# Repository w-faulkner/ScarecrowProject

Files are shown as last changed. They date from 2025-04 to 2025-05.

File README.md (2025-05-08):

# Automated Scarecrow
***
### By: Jacob Crabtree, Will Faulkner, Lauren Lanham, and Rianna Mueller
### BAE 305
### Spring 2025
***
## Summary
&nbsp;&nbsp;&nbsp;&nbsp; The objective of this project was to design and implement an automated scarecrow system intended to assist farmers in deterring birds and minimizing crop yield losses. The system integrates a passive infrared (PIR) motion sensor, mounted on the head of the scarecrow. The PIR sensor can detect thermal movement from birds or other heat-emitting objects within its field of view. Upon motion detection, the system initiates a sequence that activates the DC motors that drive the movement of the scarecrow’s arms and legs, while a set of LEDs embedded in the head light up to enhance the scare effect. To provide mobility and remote operation, the entire scarecrow assembly is mounted on a motorized, remote-controlled (RC) platform. This platform is driven by two DC hobby gear motors, which are connected to a wireless control interface. The RC car is capable of multidirectional movement (forward, backward, left, and right) controlled by a handheld transmitter. This mobility allows the operator to reposition the scarecrow across a field or garden, which increases its effective coverage area and adaptability to different farming environments. The video that includes all the features of our automated scarecrow can be found [here](https://vimeo.com/1079489157/0302ad2d24?ts=0&share=copy).

<figure>  
<p align="left">  
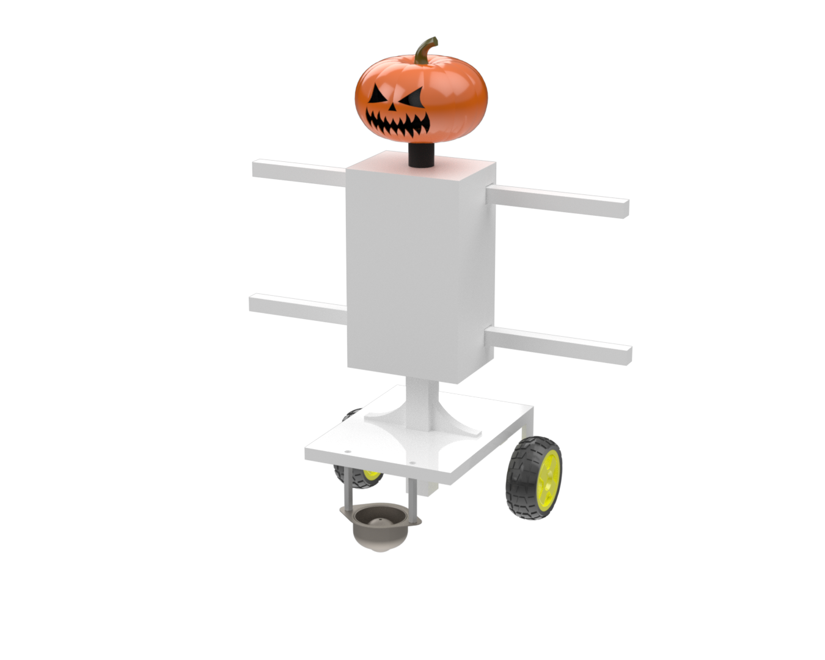
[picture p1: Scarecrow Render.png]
Scarecrow
  
<figcaption> <h6> Figure 1. The final model rendering of our scarecrow build. </figcaption>  
</figure>  
</p>  

## Design 
&nbsp;&nbsp;&nbsp;&nbsp; The automated scarecrow can be broken down into three parts: scarecrow design, the remote-controlled (RC) car, and wiring. All 3D-printable files and code are linked and can also be found in the files of this repository.
### Scarecrow

#### Materials 

* [3D printed block](https://github.com/w-faulkner/ScarecrowProject/blob/main/Modeling%20Files/block.stl)
* [3D printed bottom plate](https://github.com/w-faulkner/ScarecrowProject/blob/main/Modeling%20Files/bottomplate.stl)
* [3D printed cover](https://github.com/w-faulkner/ScarecrowProject/blob/main/Modeling%20Files/cover.stl)
* [3D printed head](https://github.com/w-faulkner/ScarecrowProject/blob/main/Modeling%20Files/head.stl)
* [3D printed main body](https://github.com/w-faulkner/ScarecrowProject/blob/main/Modeling%20Files/mainboyd.stl)
* [3D printed neck](https://github.com/w-faulkner/ScarecrowProject/blob/main/Modeling%20Files/neck.stl)
* [3D printed pin](https://github.com/w-faulkner/ScarecrowProject/blob/main/Modeling%20Files/pin.stl)
* [3D printed pin cap](https://github.com/w-faulkner/ScarecrowProject/blob/main/Modeling%20Files/pincap.stl)
* [3D printed post](https://github.com/w-faulkner/ScarecrowProject/blob/main/Modeling%20Files/post.stl)
* [3D printed scotch](https://github.com/w-faulkner/ScarecrowProject/blob/main/Modeling%20Files/scotch.stl)
* [3D printed top plate](https://github.com/w-faulkner/ScarecrowProject/blob/main/Modeling%20Files/topplate.stl)
* [3D printed yoke](https://github.com/w-faulkner/ScarecrowProject/blob/main/Modeling%20Files/yoke.stl)
* 2 –  [1 ft bamboo square dowels](https://www.amazon.com/Lugailly-Square-Wood-Dowels-Woodworking/dp/B0CZJGM1Y3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)
* 4 - [Eye hooks](https://www.amazon.com/FramePac-Small-Screw-Short-Screweyes/dp/B07R837Y69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)
* 2 - [J-style hooks](https://www.amazon.com/IDEALSV-Antique-Ceiling-Vintage-Jewelry/dp/B089N325DP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)
* [Velcro](https://www.amazon.com/Adhesive-Interlocking-Fastener-Adhesion-reclosable/dp/B09HTT768S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)
* 2 – [RGB LED](https://www.sparkfun.com/led-assorted-20-pack.html)
* [AMS312 Mini Pyroelectric PIR Human Sensor Module](https://www.amazon.com/dp/B07RT7MK7C?ref=ppx_yo2ov_dt_b_fed_asin_title)
* 2 – [N20 D.C. gear motor](https://www.amazon.com/HiLetgo-GA12-N20-Reduction-Deceleration-Multiple/dp/B0CHRWJFMD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)
* [Super Glue](https://www.amazon.com/Gorilla-Super-Glue-gram-Clear/dp/B082XGL21J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) 

#### Build Procedure

&nbsp;&nbsp;&nbsp;&nbsp; The initial phase of the project focused on constructing the physical structure of the scarecrow. This began with CAD modeling and 3D printing all necessary components. To ensure structural integrity, the top and bottom plates were adhesively bonded to the central chassis of the scarecrow using super glue, allowing adequate curing time for secure attachment. For the articulation mechanism, pilot holes were drilled into each of the yoke spacers using a precision drill bit. These holes allowed for the insertion of small eye hooks, which serve as mechanical linkage points for the scarecrow’s limbs. The component initially labeled “block” in the CAD files was later renamed “yoke spacer” for clarity. The yoke assembly was then inserted and fixed into place with adhesive. A 3D-printed pin was inserted through the rear opening of the body, and the assembly components (yoke spacer, yoke, and pin cap) were sequentially mounted onto the pin. This procedure was repeated for both N20 gear motor assemblies, ensuring symmetric actuation of the limbs. Following the installation of the yoke mechanisms, the N20 gear motors were positioned into their respective motor housings and secured. Scotch yokes were then mounted onto the motor output shafts and mechanically linked to the yoke assemblies. Additional eye bolts were threaded into the pre-drilled holes on the yoke spacers to establish the attachment points for the limbs. A close-up image of the scotch yoke mechanism used can be seen in Figure 2. The limb assembly utilized 12-inch bamboo dowels, which were cut in half to form both the arms and legs. Each dowel segment had a pilot hole drilled at one end to allow for the installation of J-hooks. The dowels were inserted through designated openings on the main body, and the J-hooks were connected to the eye bolts on the yoke spacers, completing the limb articulation system. For the head unit, two LEDs were embedded into a pumpkin-shaped enclosure to simulate eyes, and a passive infrared (PIR) motion sensor was installed to detect thermal activity on top. The neck component was affixed to the bottom of the head and then bonded to the top of the main body using adhesive. A post was subsequently glued to the bottom of the body to provide additional structural support and integration with the mobile platform. To complete the assembly, Velcro strips were attached to both the main body and its removable cover. This allows the internal wiring and electronic components to be concealed while still enabling easy access for maintenance or adjustments.
<figure>  
<p align="left">  
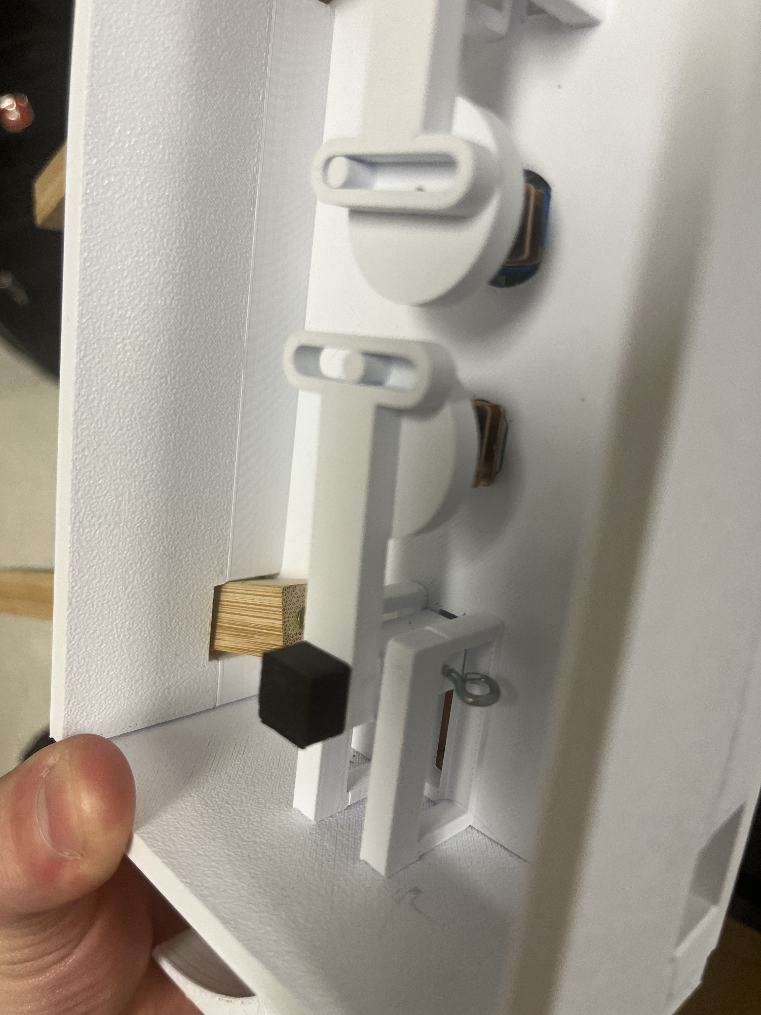
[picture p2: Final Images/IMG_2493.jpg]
  
<figcaption> <h6> Figure 2. An image of the scotch yoke mechanism used to move to arms and legs of the scarecrow. </figcaption>  
</figure>  
</p>  

### RC Car

#### Materials 

* [3D printed car base](https://github.com/w-faulkner/ScarecrowProject/blob/main/Modeling%20Files/car_base.stl)
* 2 – [140 RPM D.C. Hobby Gearmotors](https://www.sparkfun.com/hobby-gearmotor-140-rpm-pair.html)
* [Flange Mount Ball Transfer](https://www.mcmaster.com/5674K1/)
* [Female Threaded Hex Standoffs 1.5](https://www.mcmaster.com/91115A146/)
* [Velcro](https://www.amazon.com/Adhesive-Interlocking-Fastener-Adhesion-reclosable/dp/B09HTT768S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)
* 2 - [65 mm wheels](https://www.sparkfun.com/wheel-65mm-rubber-tire-pair.html)
* 4 – [10-32 Machine Screws](https://www.mcmaster.com/90272A829/)

#### Build Procedure 

&nbsp;&nbsp;&nbsp;&nbsp; The construction of the RC car base for the scarecrow platform involved a straightforward mechanical integration of components. A flange-mounted ball transfer unit was affixed to a pair of hex standoffs using two 10-32 machine screws. The opposing ends of the hex standoffs were then secured to the baseplate of the RC platform using an additional pair of 10-32 machine screws, forming a stable tricycle-style support configuration. To mount the DC hobby gear motors, Velcro strips were applied to both the flat surface of each motor casing and the inner surfaces of their respective motor tabs. This configuration provided a non-permanent but secure method of attachment, enabling straightforward removal and reinstallation during testing or maintenance. The motors were oriented such that the drive wheels extended beneath the car’s base, ensuring ground clearance and proper weight distribution.

### Wiring

#### Materials 

* 2 – [330 Ohm Resistors](https://www.sparkfun.com/resistor-330-ohm-1-4-watt-pth-20-pack-thick-leads.html)
* [433 MHz Wireless Remote Control and Mini Receiver](https://www.amazon.com/dp/B09P89RF8R?ref=ppx_yo2ov_dt_b_fed_asin_title&th=1)
* [Push button](https://www.sparkfun.com/mini-pushbutton-switch.html)
* [Two-way switch](https://www.sparkfun.com/mini-power-switch-spdt.html)
* 2 – [Dual TB6612FNG Motor Driver](https://www.sparkfun.com/sparkfun-motor-driver-dual-tb6612fng-with-headers.html)
* 2 – [Arduino Uno Microcontroller](https://www.sparkfun.com/sparkfun-redboard-qwiic.html)
* 2 – [10 by 30 row prototyping breadboards](https://www.sparkfun.com/breadboard-self-adhesive-white.html)
* [Various wires with male and female connecting ends](https://www.amazon.com/Breadboard-Solderless-Prototype-Arduino-Project/dp/B09M9YFDQQ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)

#### Build Procedure 

&nbsp;&nbsp;&nbsp;&nbsp; The electrical design of the system required the implementation of two independent circuits, each controlled by a dedicated Arduino Uno microcontroller (Figure 3). Due to the distinct and asynchronous functionalities of the scarecrow and the RC car platform, isolating these subsystems onto separate microcontrollers improved modularity and reduced the complexity of the wiring architecture. The primary circuit is responsible for the scarecrow’s functionality, encompassing the core actuation and sensing features. This circuit controlled the motion of the limbs via motor drivers and responded to motion input detected by the PIR sensor. Given the scope of its operation, special consideration was given to designing this control system in a streamlined and manageable manner to ensure reliability and ease of troubleshooting. To maintain a clean and organized wiring layout, the RC car control circuit was implemented on a separate Arduino Uno board. This decision eliminated the need for excessive wiring between distant components, thereby reducing electrical noise and physical clutter. The configuration of these circuits is based on earlier laboratory prototypes developed during the course, which informed the final layout and sequence of integration. As a result, the development of the RC subsystem was deferred until the final stages of the build, leveraging prior knowledge and successful test results.
 
<figure>  
<p align="left">  
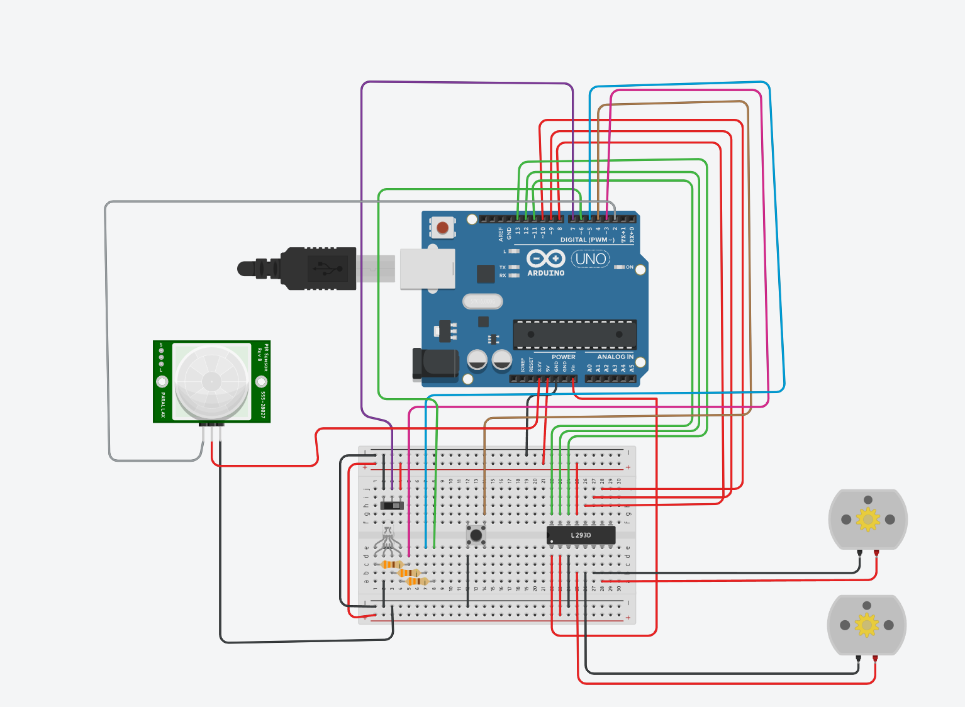
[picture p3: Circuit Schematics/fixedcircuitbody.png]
Scarecrow Body Circuit
  
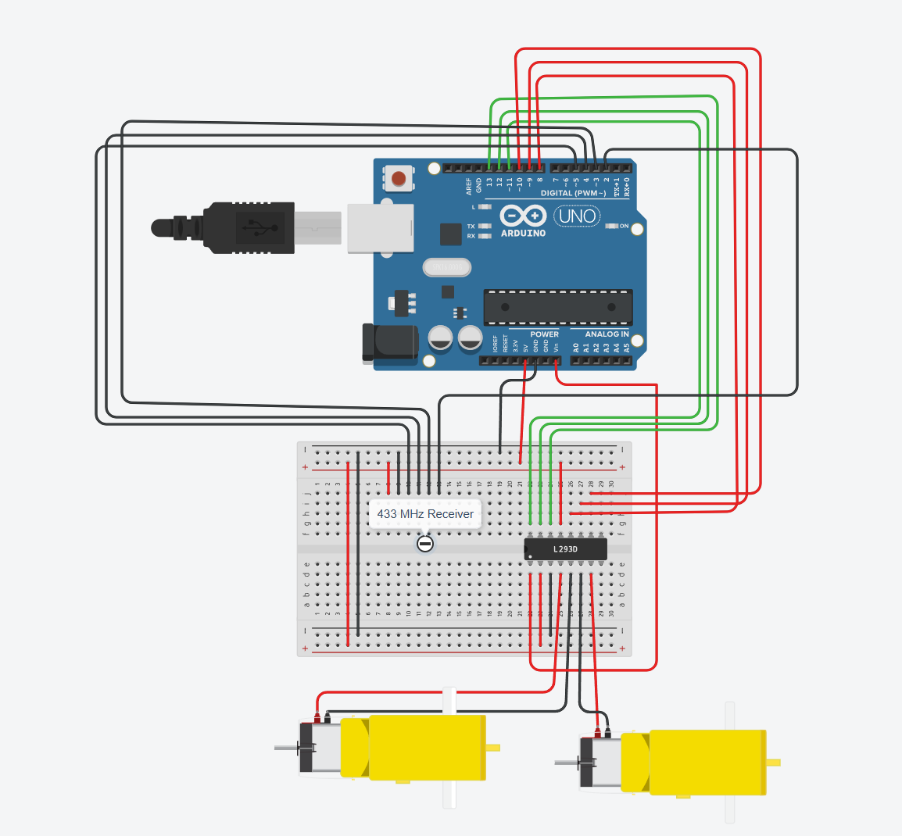
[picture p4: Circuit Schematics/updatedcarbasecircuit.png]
R.C. Car Base Circuit
  
<figcaption> <h6> Figure 3. The wiring diagrams for the scarecrow body (top) and the R.C. car base (bottom)</figcaption>  
</figure>  
</p>  

### Testing
&nbsp;&nbsp;&nbsp;&nbsp; Following the completion of the mechanical assembly, a series of functional tests were conducted using modular code segments. Individual test scripts were written and executed for each subsystem to validate proper operation prior to full integration. These tests included verification of LED functionality, motion detection via the PIR sensor, motor-driven limb articulation, and directional movement of the RC car. This incremental testing approach not only ensured that all individual components were operating as intended, but also facilitated the development of modular code blocks that could later be combined into the final integrated control program. By verifying the behavior of each subsystem in isolation, potential issues were identified and resolved early in the development cycle. All testing was performed using two Arduino Uno microcontrollers programmed via the Arduino IDE on a compatible laptop. This platform provided a reliable environment for compiling, uploading, and debugging code for both the scarecrow and the RC car systems.

### Design Discussion

&nbsp;&nbsp;&nbsp;&nbsp; The mechanical design of the scarecrow body and the RC car base underwent multiple iterations to meet functional and practical requirements. Initial concepts aimed to translate the rotational motion of the DC motors into oscillatory limb movement using a traditional crank-arm mechanism. However, after early prototyping and performance analysis, the crank-arm design was replaced by a scotch yoke system. The scotch yoke mechanism proved to be superior for this application, offering simpler assembly, smoother operation, and more consistent motion output. Notably, it enables the generation of near-perfect simple harmonic motion, ensuring symmetrical and repeatable vertical displacement of the limbs with each motor cycle—an essential feature for the scarecrow’s deterrent effect. In parallel, the RC car platform also underwent critical revisions. The original steering configuration utilized a rigid front axle with dual 65 mm wheels (sourced from SparkFun), intended to improve maneuverability. However, due to the axle’s solid design, both wheels rotated in unison, causing significant resistance during turns and leading to frequent drag or complete steering failure. This issue was resolved by replacing the front axle assembly with a single ball transfer unit, which significantly improved the platform’s turning radius, acceleration response, and general mobility. Stability at higher speeds remained a concern due to the scarecrow’s elevated center of gravity. While mitigations were applied, further investigation into alternative front-end configurations such as dual independent wheel assemblies or articulated front steering would be pursued in extended development cycles. The electrical integration and control strategy also underwent several iterations. To ensure modularity and facilitate both mobility and autonomous scarecrow behavior, two Arduino Uno microcontrollers were utilized. The first microcontroller managed the scarecrow’s operation, including the LED “eyes,” PIR motion sensor, and the actuation of the arms and legs via DC gear motors. The second Arduino Uno controlled the RC car’s movement via a wireless remote control system comprising of a mini 4-channel receiver module and a corresponding handheld transmitter. The RC control interface was implemented using digital high/low signal mapping, where each button press on the transmitter triggered directional motion (forward, reverse, left, right) through corresponding motor outputs. Both microcontrollers were powered from a 4-cell AA battery pack, wired directly to one Arduino and daisy-chained to the second via the VIN and GND rails. While this configuration simplified power distribution and battery replacement, extended operation under full motor load resulted in significant current draw, leading to voltage drops and reduced operational duration. This observation suggests that future revisions should consider more robust power management solutions, including integrated rechargeable battery packs or solar charging modules to support sustained deployment in agricultural environments. To facilitate flexible operation modes, a single-pole dual-throw (SPDT) slider switch was added to toggle between manual operation and motion detection modes. In manual mode, the system allows for repositioning or transport without unintentional activation of the PIR-triggered motion system. Additionally, a momentary push-button switch was integrated to enable functional testing of the scarecrow’s LEDs and motor systems without relying on sensor input.

## Testing
### Scarecrow Body Code
```c
/*
  BAE 305
  Automated Scarecrow Project
  This is the code to control the the movements and LEDs on the scarecrow as well as motion detecting
  By: Jacob Crabtree
*/
// Inputs
const int switchPin = 7;  // SPDT switch
const int buttonPin = 4;  // Button input
const int pirPin = 2;     // PIR sensor input

// LEDs
const int redLED = 3;
const int greenLED = 5;

// Right motor
const int AIN1 = 13;
const int AIN2 = 12;
const int PWMA = 11;

// Left motor
const int BIN1 = 8;
const int BIN2 = 9;
const int PWMB = 10;

bool buttonPrevState = HIGH;  // Button is pulled up
bool motionPrevState = LOW;

enum Mode { BUTTON, MOTION };
Mode currentMode = BUTTON;

void setup() {
  Serial.begin(9600);

  pinMode(switchPin, INPUT);  // Read from SPDT switch
  pinMode(buttonPin, INPUT_PULLUP);
  pinMode(pirPin, INPUT);

  pinMode(redLED, OUTPUT);
  pinMode(greenLED, OUTPUT);

  pinMode(AIN1, OUTPUT);
  pinMode(AIN2, OUTPUT);
  pinMode(PWMA, OUTPUT);
  pinMode(BIN1, OUTPUT);
  pinMode(BIN2, OUTPUT);
  pinMode(PWMB, OUTPUT);

  setGreen();
  stopMotors();
  Serial.println("Mode: BUTTON");
}

void loop() {
  // Read switch position and set mode
  bool switchState = digitalRead(switchPin);
  Mode newMode = (switchState == LOW) ? BUTTON : MOTION;

  // Change mode if necessary
  if (newMode != currentMode) {
    currentMode = newMode;
    stopMotors();
    setGreen();
    Serial.print("Mode: ");
    Serial.println(currentMode == BUTTON ? "BUTTON" : "MOTION");
  }

  // Button mode logic
  if (currentMode == BUTTON) {
    bool buttonPressed = digitalRead(buttonPin) == LOW;
    if (buttonPressed && buttonPrevState == HIGH) {
      Serial.println("Button pressed!");
      runSequence();
    }
    buttonPrevState = buttonPressed;

  } 
  // Motion mode logic
  else if (currentMode == MOTION) {
    bool motionDetected = digitalRead(pirPin) == HIGH;
    if (motionDetected && motionPrevState == LOW) {
      Serial.println("Motion detected!");
      runSequence();
    }
    motionPrevState = motionDetected;
  }
}

void runSequence() {
  setRed();
  runMotors();
  delay(7000);
  stopMotors();
  setGreen();
}

void runMotors() {
  digitalWrite(AIN1, HIGH);
  digitalWrite(AIN2, LOW);
  analogWrite(PWMA, 255);

  digitalWrite(BIN1, HIGH);
  digitalWrite(BIN2, LOW);
  analogWrite(PWMB, 255);
}

void stopMotors() {
  analogWrite(PWMA, 0);
  analogWrite(PWMB, 0);
}

void setRed() {
  digitalWrite(redLED, HIGH);
  digitalWrite(greenLED, LOW);
}

void setGreen() {
  digitalWrite(redLED, LOW);
  digitalWrite(greenLED, HIGH);
}
```

### R.C. Car Code
```c
/*
  BAe 305
  Automated Scarecrow Project
  This is the code to control the R.C. Car base of the build
  By: Jacob Crabtree
*/
// Motor driver pins
const int AIN1 = 13; // Right motor
const int AIN2 = 12;
const int PWMA = 11;

const int PWMB = 10; // Left motor
const int BIN2 = 9;
const int BIN1 = 8;

// RF receiver inputs
const int FORWARD_PIN = 2;
const int BACKWARD_PIN = 3;
const int LEFT_PIN = 4;
const int RIGHT_PIN = 5;

void setup() {
  // Motor pins
  pinMode(AIN1, OUTPUT);
  pinMode(AIN2, OUTPUT);
  pinMode(PWMA, OUTPUT);

  pinMode(BIN1, OUTPUT);
  pinMode(BIN2, OUTPUT);
  pinMode(PWMB, OUTPUT);

  // Receiver inputs
  pinMode(FORWARD_PIN, INPUT);
  pinMode(BACKWARD_PIN, INPUT);
  pinMode(LEFT_PIN, INPUT);
  pinMode(RIGHT_PIN, INPUT);

  Serial.begin(9600);
}

void loop() {
  bool forward = digitalRead(FORWARD_PIN);
  bool backward = digitalRead(BACKWARD_PIN);
  bool left = digitalRead(LEFT_PIN);
  bool right = digitalRead(RIGHT_PIN);

  // Stop motors by default
  stopMotors();

  if (forward) {
    Serial.println("Forward");
    moveForeward();
  } else if (backward) {
    Serial.println("Backward");
    moveBackward();
  } else if (left) {
    Serial.println("Left");
    turnLeft();
  } else if (right) {
    Serial.println("Right");
    turnRight();
  }

  delay(50); // Small delay to avoid flooding serial monitor
}

// === Motor control functions ===

void moveBackward() {
  digitalWrite(AIN1, HIGH);
  digitalWrite(AIN2, LOW);
  analogWrite(PWMA, 255);  // Right motor at full speed

  digitalWrite(BIN1, HIGH);
  digitalWrite(BIN2, LOW);
  analogWrite(PWMB, 255);  // Left motor at full speed
}

void moveForeward() {
  digitalWrite(AIN1, LOW);
  digitalWrite(AIN2, HIGH);
  analogWrite(PWMA, 255);  // Right motor at full speed

  digitalWrite(BIN1, LOW);
  digitalWrite(BIN2, HIGH);
  analogWrite(PWMB, 255);  // Left motor at full speed
}

void turnRight() {
  digitalWrite(AIN1, LOW);
  digitalWrite(AIN2, HIGH);
  analogWrite(PWMA, 190);  // Right motor at full speed

  digitalWrite(BIN1, LOW);
  digitalWrite(BIN2, HIGH);
  analogWrite(PWMB, 255);  // Left motor at full speed
}

void turnLeft() {
  digitalWrite(AIN1, LOW);
  digitalWrite(AIN2, HIGH);
  analogWrite(PWMA, 255);  // Right motor at full speed

  digitalWrite(BIN1, LOW);
  digitalWrite(BIN2, HIGH);
  analogWrite(PWMB, 190);  // Left motor at full speed
}

void stopMotors() {
  analogWrite(PWMA, 0); // Stop right motor
  analogWrite(PWMB, 0); // Stop left motor
}
```
### Procedure 

&nbsp;&nbsp;&nbsp;&nbsp; To validate the functionality of the prototype, a systematic testing procedure was employed, beginning with the verification of the primary scarecrow subsystem. As the arm and leg actuators and LEDs were integrated into the control circuit, initial testing focused on verifying their coordinated operation. Upon initial execution, the system failed to respond as expected, necessitating code debugging and parameter tuning within the Arduino environment. Once revised, the updated firmware successfully enabled synchronized movement of the limbs and activation of the LEDs in response to motion input. Subsequent testing addressed the mobility of the RC car platform. Initial trials were conducted without the wireless receiver connected to ensure basic motor function and wiring integrity. Upon confirming proper motor operation, the wireless RC module was integrated into the system, and the code was updated to accommodate remote input signals. The platform demonstrated consistent forward and reverse movement, with limited but functional lateral steering. A final integration test was performed to simulate field deployment. The fully assembled system was navigated through a constructed obstacle course comprising tables, chairs, and miscellaneous obstructions. Upon reaching the designated position, the scarecrow was placed into “detection mode.” A heat-emitting object (i.e., a human hand) was then introduced at varying heights and distances to evaluate the range and responsiveness of the PIR sensor. Multiple trials were conducted to determine detection consistency across angles and distances representative of typical bird flight paths.

### Results

&nbsp;&nbsp;&nbsp;&nbsp; Following system debugging and iterative testing, the prototype achieved expected operational performance. The coordinated movement of limbs and LED activation occurred reliably upon PIR sensor triggering. The RC platform successfully supported basic mobility; however, limitations in turning radius and stability were observed. Notably, the system tended to tip laterally during high-speed turns, likely due to the elevated center of mass imposed by the scarecrow’s structure. Furthermore, during extended operation, battery depletion became evident, necessitating frequent replacement to maintain performance. These limitations, while manageable during testing, suggest areas for improvement in future design iterations, such as implementing onboard solar charging capabilities.

### Discussion
&nbsp;&nbsp;&nbsp;&nbsp; The RC mobility system demonstrated adequate forward and reverse motion, with steering performance constrained by the platform’s geometry. Increasing the turning capability introduced additional instability, particularly during rapid directional changes, where the scarecrow’s top-heavy design contributed to tipping risks. To address this, future designs should consider alternate drive configurations, such as a dual-axle steering mechanism or a four-wheel skid-steer approach, to enhance stability and maneuverability. The actuation system for the scarecrow limbs functioned in accordance with design specifications. The motion profile achieved a balance between aggressive movement sufficient to deter birds and restrained force that preserved platform stability. LED brightness was suitable for visual effect, with enhanced visibility in low-light conditions. The PIR sensor, initially a point of concern due to its directional sensitivity, was found to perform within acceptable tolerances. Experimental testing confirmed the sensor could detect motion from common approach vectors, including side angles, thereby satisfying the requirements for bird detection in an open field environment. Overall, the prototype met all core functional objectives. While improvements could be made to enhance durability, stability, and power efficiency, the current design effectively demonstrates the feasibility of a mobile, autonomous scarecrow platform as a proof-of-concept prototype.

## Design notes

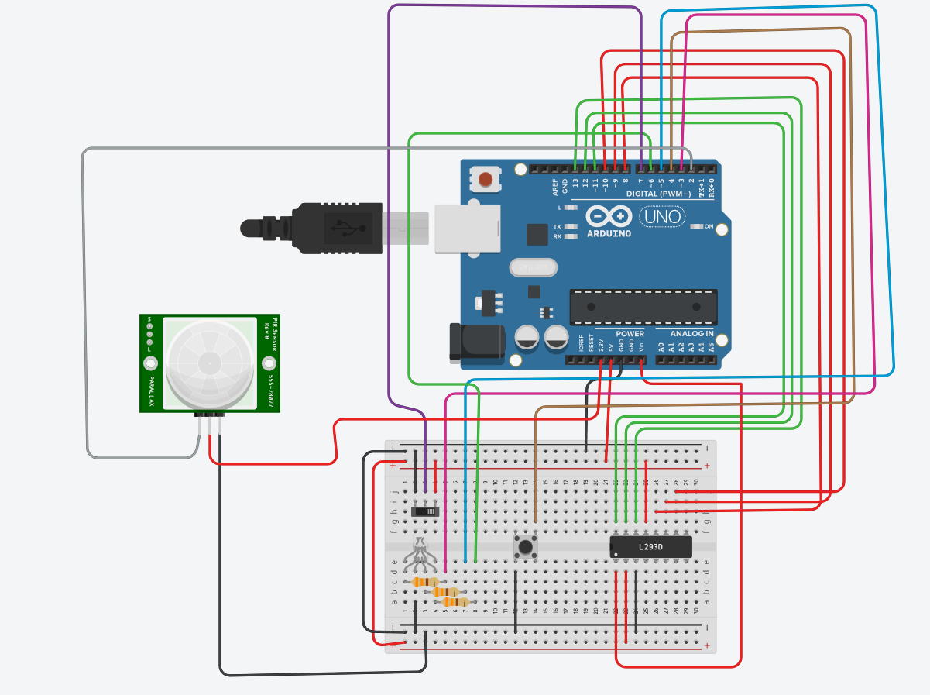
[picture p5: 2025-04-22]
Circuit Schematics/scarecrowbodycircuit.png

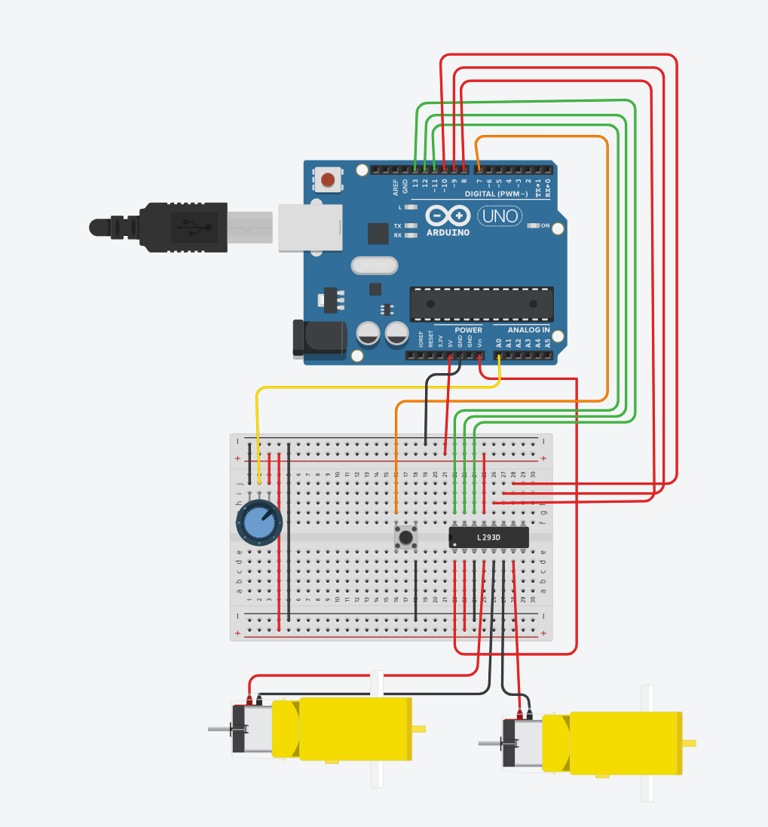
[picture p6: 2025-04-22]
Circuit Schematics/carbase.png

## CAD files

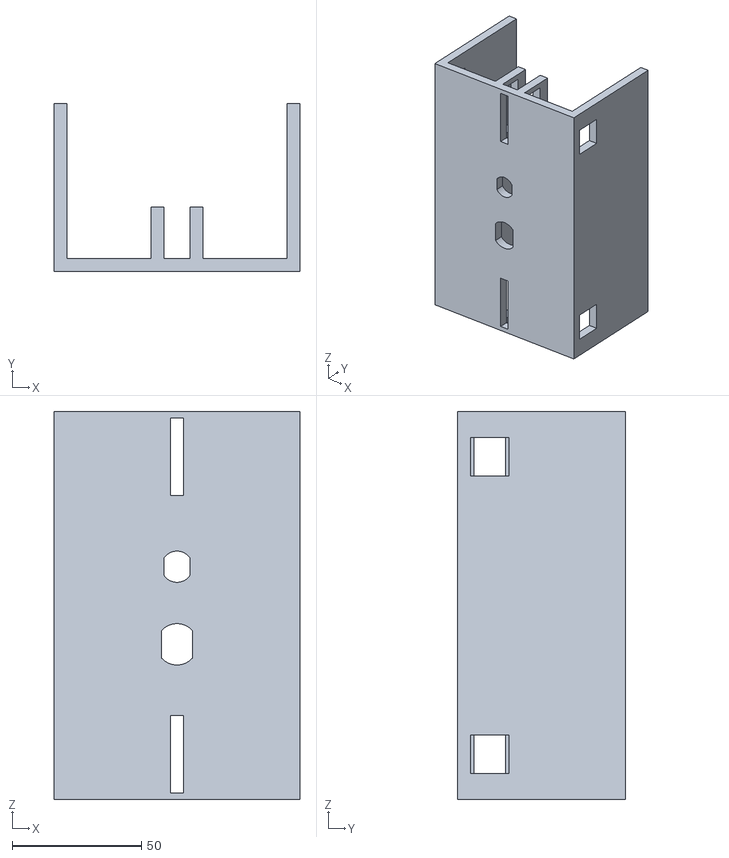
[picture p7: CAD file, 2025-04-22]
Modeling Files/mainboyd.stl
95.0 x 65.0 x 150.0

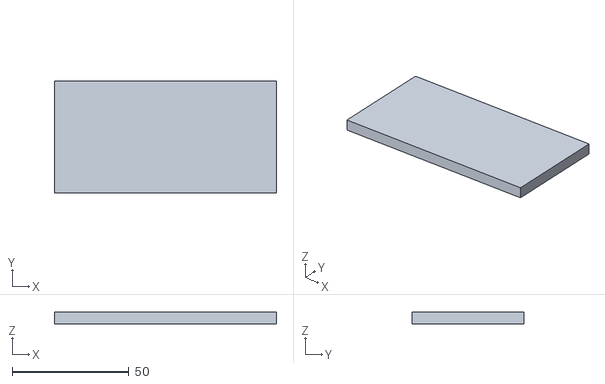
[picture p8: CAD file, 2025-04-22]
Modeling Files/bottomplate.stl
95.0 x 48.0 x 5.00

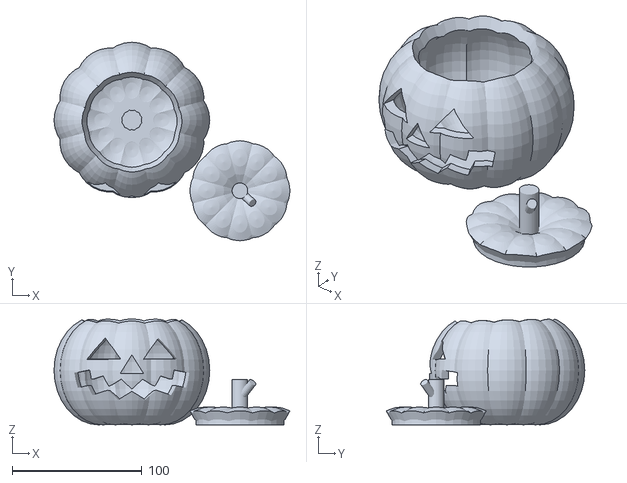
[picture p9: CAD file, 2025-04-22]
Modeling Files/head.stl
182.1 x 153.3 x 81.6

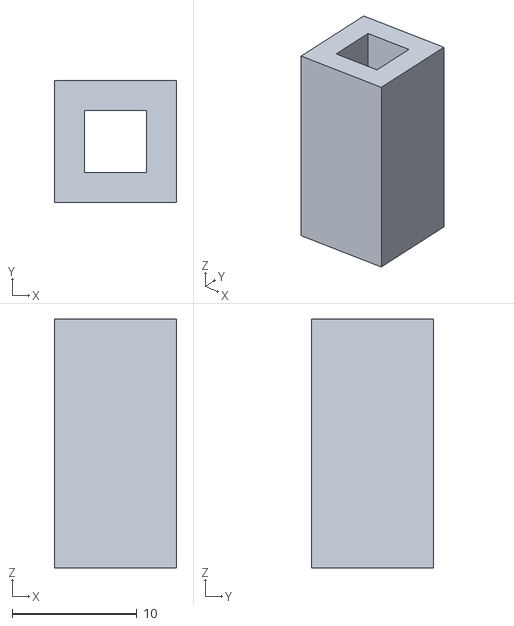
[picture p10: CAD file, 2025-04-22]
Modeling Files/block.stl
9.80 x 9.80 x 20.0

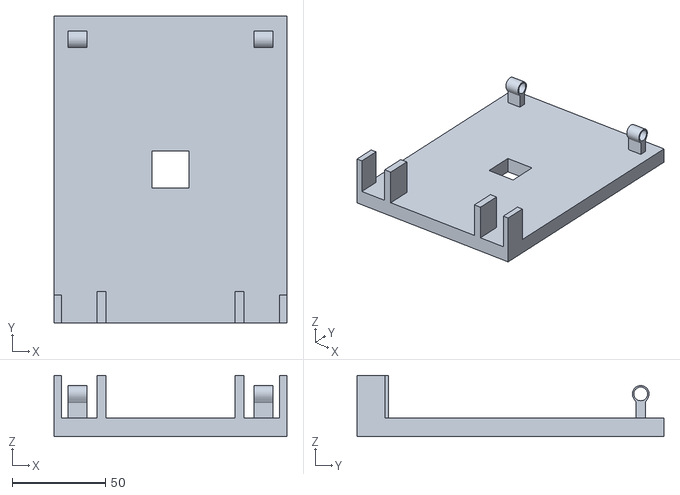
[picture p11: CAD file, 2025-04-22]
Modeling Files/car_base.stl
125.0 x 165.0 x 33.0

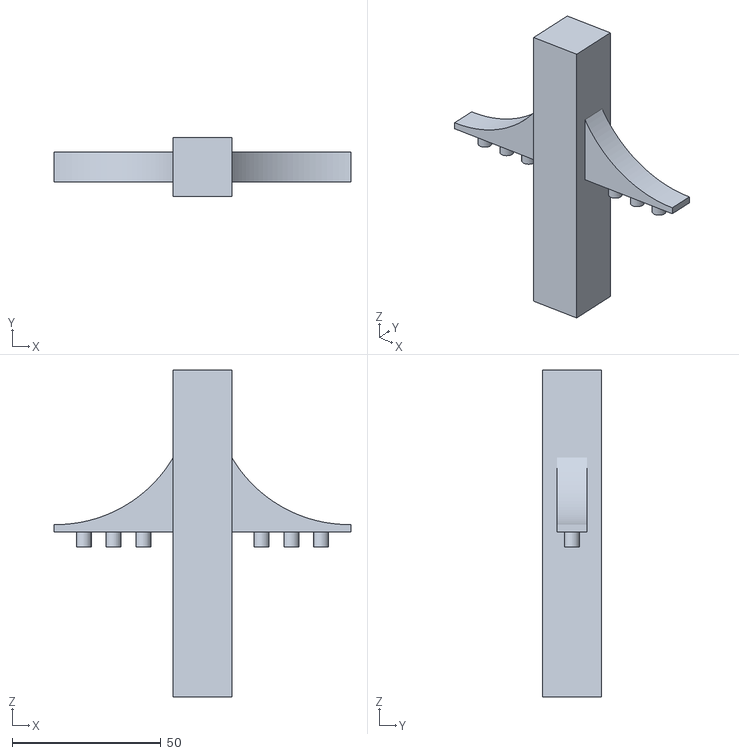
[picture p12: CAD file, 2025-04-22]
Modeling Files/post.stl
99.8 x 19.7 x 110.0

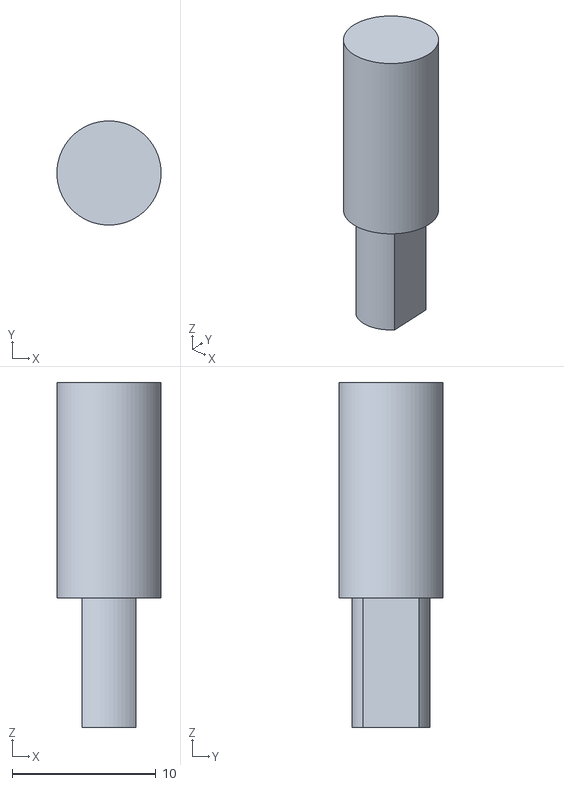
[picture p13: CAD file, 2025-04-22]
Modeling Files/axel.stl
7.25 x 7.24 x 24.0

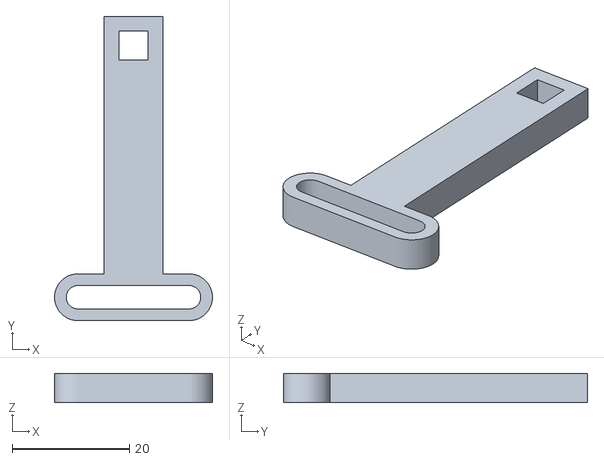
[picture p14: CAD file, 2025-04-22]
Modeling Files/yoke.stl
27.0 x 52.0 x 5.00

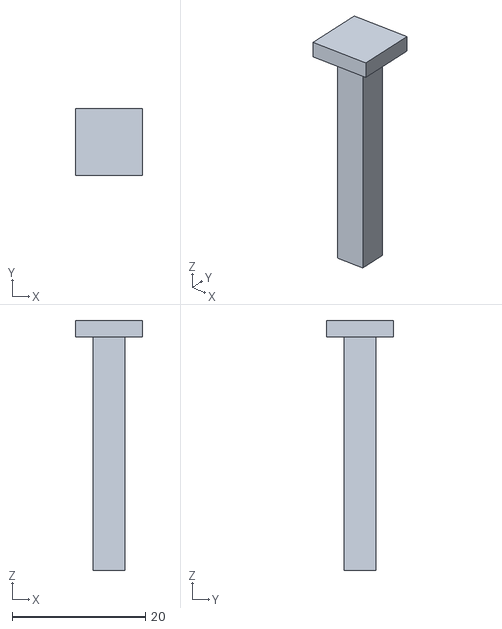
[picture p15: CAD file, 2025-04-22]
Modeling Files/pin.stl
10.0 x 10.0 x 37.5

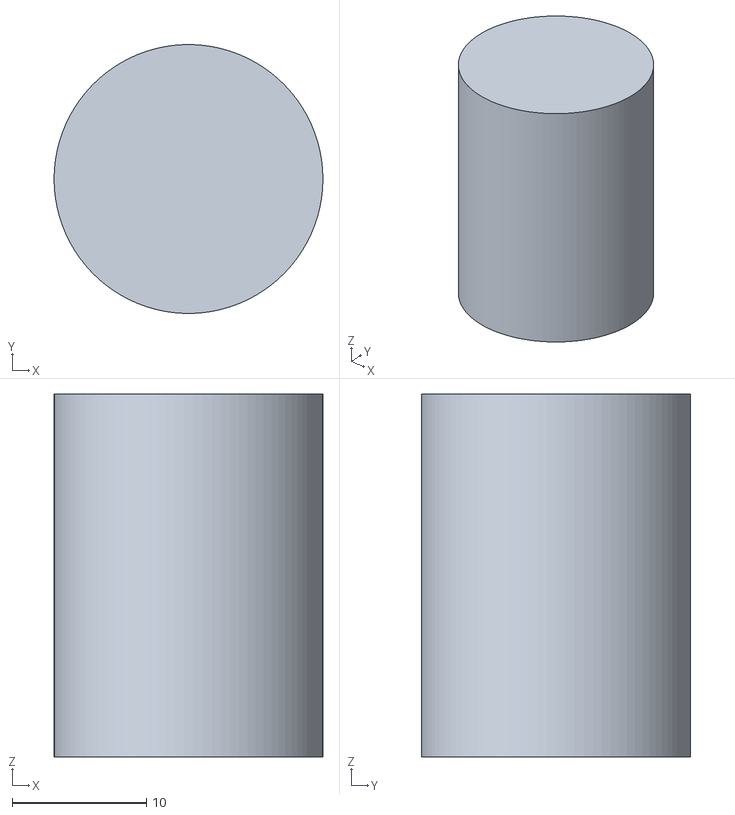
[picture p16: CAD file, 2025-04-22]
Modeling Files/neck.stl
20.0 x 20.0 x 27.0

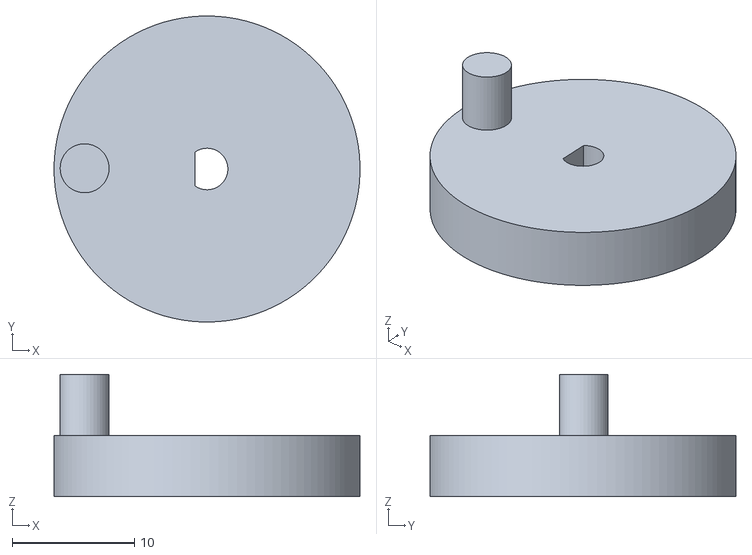
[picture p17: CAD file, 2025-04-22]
Modeling Files/scotch.stl
25.0 x 25.0 x 10.0

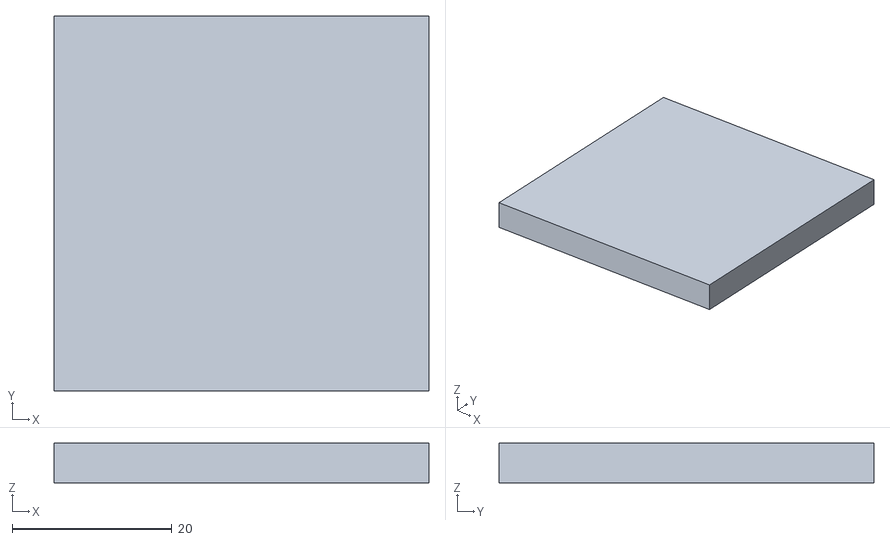
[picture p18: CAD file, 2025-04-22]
Modeling Files/topplate.stl
47.0 x 47.0 x 5.00

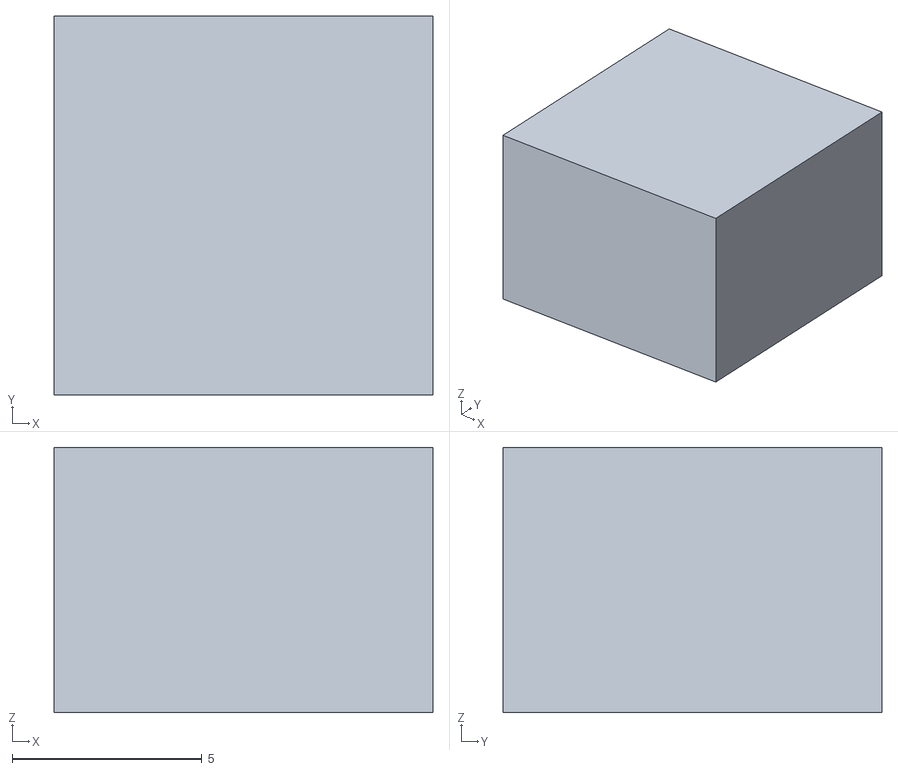
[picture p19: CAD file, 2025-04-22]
Modeling Files/pincap.stl
10.0 x 10.0 x 7.00

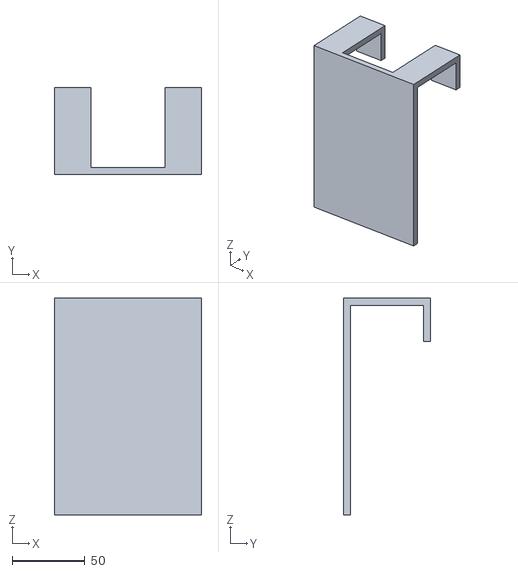
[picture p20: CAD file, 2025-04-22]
Modeling Files/cover.stl
101.0 x 60.0 x 149.0

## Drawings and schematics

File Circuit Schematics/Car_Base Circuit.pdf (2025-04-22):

A

1 | 2 | 3 | 4 | 5 | 6

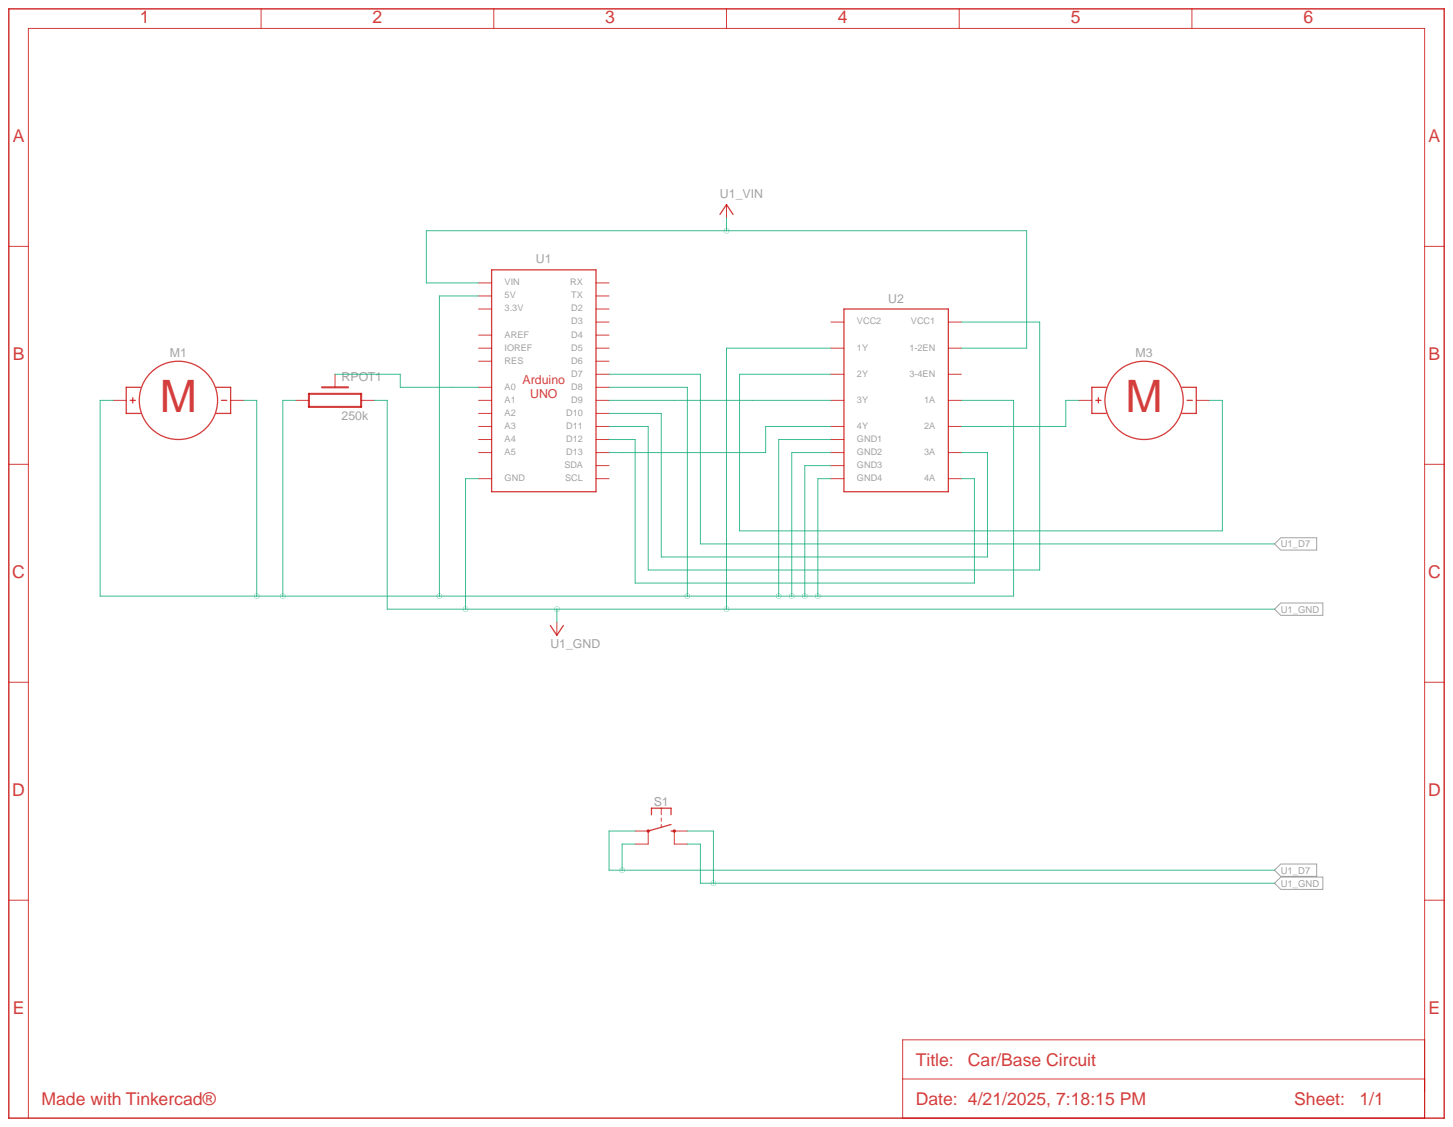
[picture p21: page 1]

Title: Car/Base Circuit

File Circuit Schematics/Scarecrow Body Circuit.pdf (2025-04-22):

A

1 | 2 | 3 | 4 | 5 | 6

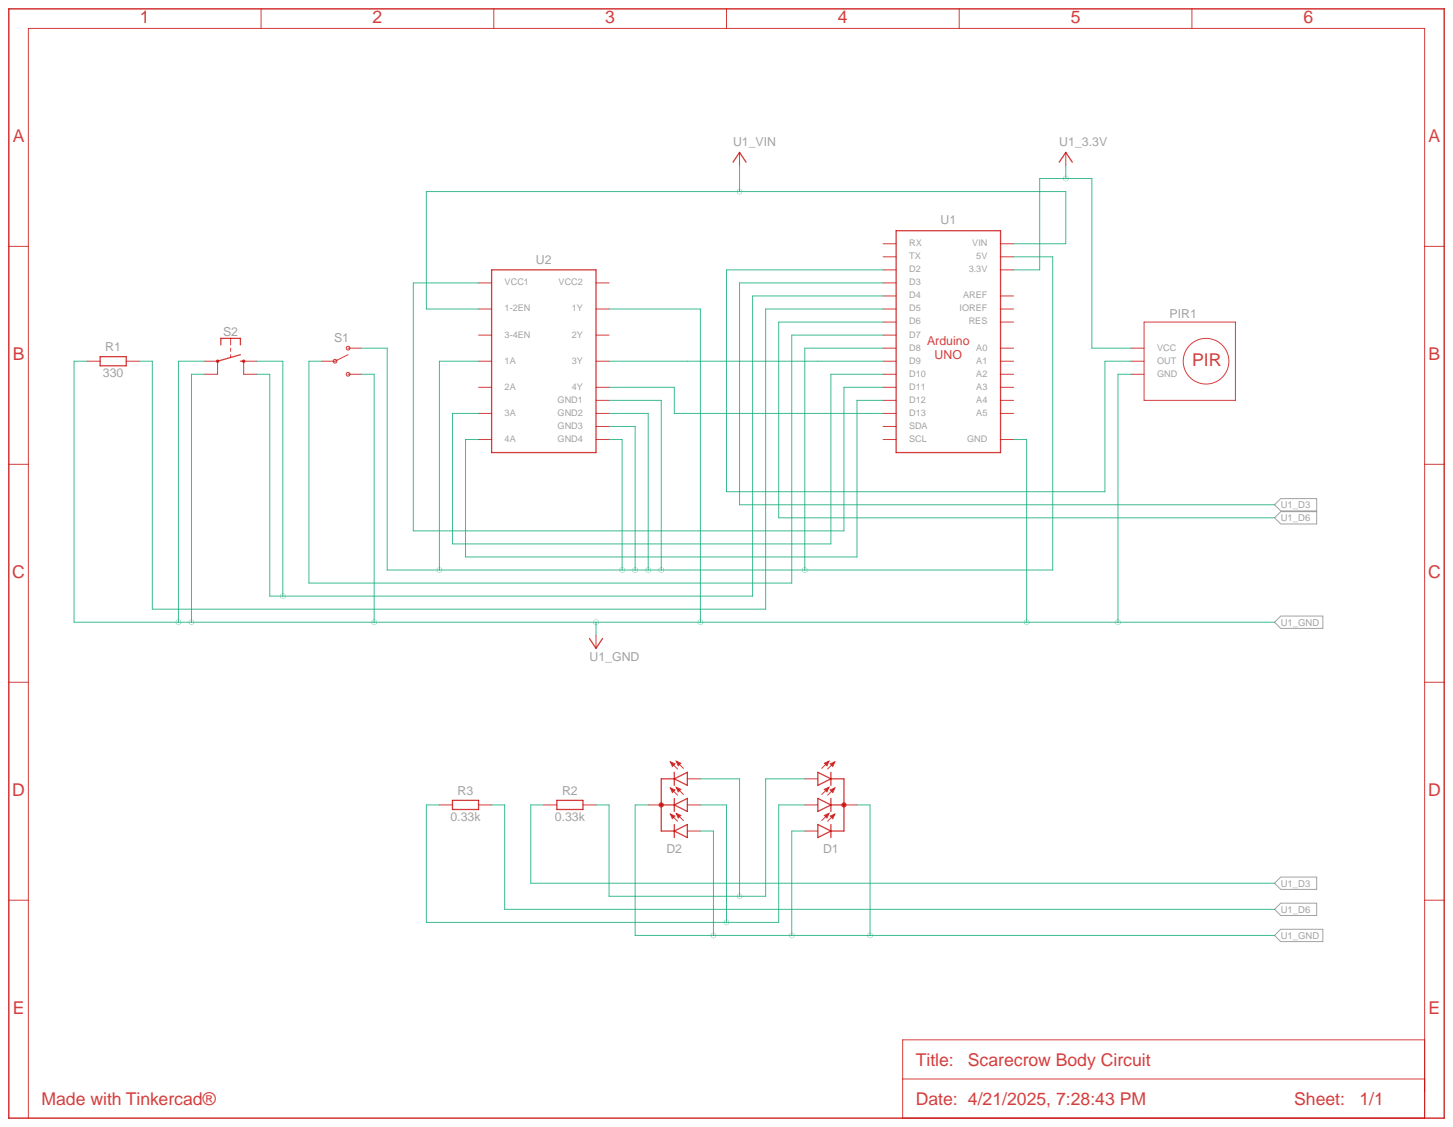
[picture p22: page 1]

Title: Scarecrow Body Circuit
